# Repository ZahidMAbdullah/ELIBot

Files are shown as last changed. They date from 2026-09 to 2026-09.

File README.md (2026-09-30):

# ELIBot — Mechatronics Laboratory (Robot: Advanced)

**ELIBot** is a four-wheeled, all-terrain robot with spiked/clawed wheels, developed by a team of five undergraduate students for the *Mechatronics Laboratory (Robot: Advanced)* course at Kyoto University of Advanced Science (KUAS). Designed to navigate a challenging obstacle course—including a door, uneven terrain, slope, ditch, QR-code checkpoint, ledge, roller obstacle, speed bump, stairs, a traffic-light-controlled barrier, and an object-retrieval task—the robot combines a raised, high-clearance chassis, custom rigid/flexible claw wheels, and a lightweight single-DOF manipulator arm. It's primarily teleoperated from a remote operator station, watching fixed cameras placed along the course (plus an optional onboard camera feed), with support for minimal autonomous behaviors (e.g. reacting to the traffic light on its own) layered on top.

> This repository documents the full design process — from the original tri-wheel concept to the final ELIBot — along with its firmware, ROS2 software stack, CAD/print files, and build media.

## Table of Contents

- [Team](#team)
- [What It Was Built For](#what-it-was-built-for)
- [Design Journey](#design-journey)
- [Final Design](#final-design)
  - [Mechanical](#mechanical)
  - [Manipulator Arm](#manipulator-arm)
  - [Electronics](#electronics)
  - [Software Architecture](#software-architecture)
- [Operating Instructions](#operating-instructions)
- [Repository Structure](#repository-structure)
- [Documents](#documents)
- [Media](#media)
  - [Videos](#videos)
  - [Photos](#photos)
- [Acknowledgments & References](#acknowledgments--references)
- [License](#license)

## Team

**Team 12**, Mechatronics Laboratory (Robot: Advanced), Spring 2026:

- Abdullah Al Ayaat
- G. C. Mohnish
- Catherine Ella Burtenshaw
- Daphne Jillian Gan Tan
- Muhammad Abdullah Zahid

## What It Was Built For

Mechatronics Laboratory (Robot: Advanced) is a hands-on robotics course, run over one semester, where small teams design, fabricate, and program a robot from scratch. It culminates in a robot challenge held during the course's 15th week: a field of physical obstacles that every team's robot has to get through under its own power. ELIBot is this team's entry for that challenge.

The competition field laid out a mock "street" of obstacles a mobile robot has to get through under its own locomotion and, in places, its own manipulation — pushing/opening a door, climbing a slope, crossing uneven terrain and a ditch, reading a QR checkpoint, climbing down a ledge, crossing a speed bump and a roller, climbing up and down the stairs, responding correctly to a traffic light to get a barrier opened, and picking up and carrying an object to a goal. ELIBot's design — the raised chassis and clawed wheels in particular — was driven directly by that obstacle set.

The robot had to be untethered and was operated from a fixed station with no direct line of sight to the field — the operator watched a multi-window monitor fed by fixed cameras placed along the course, optionally supplemented by the robot's own onboard camera feed on a separate laptop — with a lightweight autonomous layer handling a few specific perception-driven behaviors (QR/traffic-light detection) on top of manual driving.

## Design Journey

ELIBot went through three distinct mechanical designs:

1. **Tri-wheel concept** (original pitch): a spring-suspended front "wheel-leg" (inspired by configurable wheel-leg mechanisms in the literature) for climbing stairs/ditches, a rear pair of wheels on a 4-bar spring suspension for uneven terrain, and a top-mounted 3-DOF manipulator arm with a solenoid-driven pincher gripper.
2. **Four-wheel, front-spiked only**: the tri-wheel base proved **unstable**, so the team pivoted to a four-wheeled layout — but only the front pair used spiked/clawed wheels, with plain wheels still at the rear.
3. **Four-wheel, all-spiked** (final): the plain rear wheels in design 2 didn't grip well enough to climb the stairs, so the team switched to spiked/clawed wheels on all four corners. The manipulator arm was also simplified from 3-DOF + pincher down to a lighter 1-DOF hook mechanism, for better weight distribution and stair-climbing stability.

Designs 1 and 2 are documented here only through their presentations — [`Robot Concept Presentation/`](./Robot%20Concept%20Presentation) for design 1 (the tri-wheel concept), and [`Intermediate Presentation/`](./Intermediate%20Presentation) for the transition from design 1 to design 2 — rather than through their raw CAD/design files. Design 3, the final version that was actually built, is described below, in the [final report](./Teams12_final_report.pdf), and via the source/print files elsewhere in this repository.

## Final Design

### Mechanical

ELIBot's body has three main parts:

- **Top Chassis / Bottom Chassis** — a simple box housing the microcontroller, motor drivers, buck converter, and perfboards, with a removable Top Chassis panel for easy access; sized to be sturdy against fall/testing impacts while still easy to open.
- **Brackets / Support Brackets** — front (shorter) and rear (taller) main brackets hold the drive motors, each secured in place by a matching support bracket; sized asymmetrically to keep the robot level, shrink its turning footprint, and shift the center of mass rearward for stair climbing without tipping.
- **Cage** — a lightweight top frame protecting the 12V LiPo battery, a power bank, and the Raspberry Pi 4, and keeping wiring organized.

The signature feature is the **clawed/spiked wheel**: a rigid **PLA** inner hub (bolted to the motor shaft via a threaded brass connector) paired with a flexible **TPU** outer ring of 8 claws. The rigid hub keeps the wheel stable while the TPU claws flex on impact and grip stair edges/ledges — giving some of the benefit of a reconfigurable wheel-leg design without its mechanical complexity.

### Manipulator Arm

The arm went through the same simplification arc as the chassis: an initial 3-DOF, top-mounted arm with a solenoid-driven pincher was replaced by a **1-DOF, front-mounted "elephant trunk"** arm ending in a curved hook — lighter, mechanically simpler, and strong enough to support the robot's own weight if it tips, unlike the original pincher which broke under load during testing. The final assembly uses three servos: one for base rotation, one for the second link, one for the hook.

### Electronics

| Component | Role |
|---|---|
| STM32 Nucleo-F091RC | Real-time motor/servo control (low-level) |
| Raspberry Pi 4 Model B | ROS2 high-level control, perception, decision-making |
| 2× L298N | Motor drivers for 4 brushed DC drive motors (skid-steering) |
| PCA9685 (16-ch) | PWM driver for 3 manipulator servos, over I²C |
| Buck converter | Steps down battery voltage for logic circuitry |
| 12V LiPo + power bank | Main drive power / Raspberry Pi power |
| USB camera | Onboard vision (QR codes, traffic light) |

The Pi and STM32 communicate over USB serial at 115200 baud: the Pi sends motion/servo setpoints, the STM32 executes deterministic PWM control and echoes actuator feedback. A watchdog on the STM32 stops all motors if commands stop arriving, preventing runaways from a dropped link.

For the full wiring/circuit diagram and electrical connections between all of these components, see §2.4 ("Circuit Design") of the [final report](./Teams12_final_report.pdf).

### Software Architecture

High-level software runs as a modular **ROS2** stack on the Raspberry Pi:

```
Operator (keyboard) ─┐
                      ▼
              Teleoperation Node ── USB Serial (115200) ──▶ STM32 (motors + servos)
                      │
USB Camera ──▶ Camera Publisher Node ──/camera/image_raw──▶ Vision Status Node
                                                                  │  QR (Pyzbar) + traffic light (YOLOv8 + HSV)
                                                                  ▼
                                                         /vision_status ──▶ LED Indicator Node (GPIO)
                                                                       └──▶ Traffic-light ROS2 notification (wireless, for the barrier)
```

- **Camera publisher** — captures RGB frames via OpenCV, keeps only the latest frame to avoid perception lag.
- **Vision status node** — runs QR detection (grayscale + Pyzbar) and traffic-light detection (YOLOv8n localizes the light, HSV classifies red/yellow/green) in parallel; debounces both before publishing state changes.
- **LED indicator node** — drives GPIO LEDs based on QR detection state.
- **Teleoperation node** — converts operator keyboard input into the STM32's serial command protocol.

Firmware protocol (STM32 side): 8 slash-separated values — 4 motor duty cycles `[-1.0, 1.0]` and 4 servo angles (degrees) — terminated by `d`, e.g. `0.5/0.5/0/0/90/0/0/-45d`. See [`source-code/Nucleo_Firmware/combined_node/README.md`](./source-code/Nucleo_Firmware/combined_node/README.md) for the full protocol and pin mapping.

## Operating Instructions

1. Connect the STM32 to the Raspberry Pi 4; power the Pi from the power bank.
2. (Setup/debug) Connect via HDMI to a monitor, or view the Pi's desktop remotely, to launch ROS2 nodes from a terminal.
3. Launch, in order:
   1. `ros2 launch elibot_vision qr_led.launch.py` → starts the camera publisher, vision status node, and QR LED indicator together
   2. `ros2 run elibot_robot_ctrl motorservo_teleop_controller --port /dev/ttyACM0` → keyboard teleop, sends serial commands to the STM32
4. Disconnect the setup peripherals, connect the drive battery, and verify wheel + arm motion before running the course.

Full build/run instructions and dependencies: [`source-code/README.md`](./source-code/README.md). Full narrative details: [final report, §3](./Teams12_final_report.pdf).

The vision node can also run off-robot on a separate, more powerful machine over the network instead of on the Pi — see [`source-code/README.md`](./source-code/README.md#3-vision-node-onboard-vs-remote-deployment) for that configuration (`elibot_ros2_ws_server/`), which was used during development to experiment with heavier detection models than the Pi could run in real time.

## Repository Structure

```
.
├── README.md
├── LICENSE
├── Teams12_final_report.pdf
├── Robot Challenge and Field Details 2025.pdf
├── Robot Concept Presentation/       # superseded tri-wheel concept pitch — not the final design
├── Intermediate Presentation/        # mid-project checkpoint — shows the tri-wheel -> four-wheel transition
├── STL Files/                        # final ELIBot print files (STL), organized by body/wheels/manipulator
├── source-code/                      # firmware + ROS2 software — see its own README
│   ├── Nucleo_Firmware/              # STM32 firmware (PlatformIO/mbed): combined_node (final), motors_only/servos_only (debug isolation builds)
│   ├── elibot_ros2_ws_robot/         # ROS2 workspace deployed ON the Raspberry Pi (camera, vision, teleop)
│   └── elibot_ros2_ws_server/        # optional: vision node deployable on a separate, more powerful machine instead of the Pi
└── Media/                            # photos and video (large raw footage hosted externally)
```

## Documents

- [Final report](./Teams12_final_report.pdf) — full design writeup (this README summarizes it)
- [Challenge & field rules](./Robot%20Challenge%20and%20Field%20Details%202025.pdf)
- [Concept presentation](./Robot%20Concept%20Presentation/Concept%20Presentation%20%28Superseded%20Tri-Wheel%20Design%29.pdf) — the original tri-wheel pitch; **superseded**, describes a different robot than the one that was actually built
- [Intermediate presentation](./Intermediate%20Presentation/Intermediate%20Presentation%20%28Design%20Transition%20Checkpoint%29.pdf) — a mid-project checkpoint documenting the pivot from the tri-wheel design to the second, four-wheel design (front wheels spiked, rear wheels still plain); that rear-wheel choice and the manipulator's pincher end effector shown here were both changed again before the final design
- [Final presentation video (Week 15)](https://drive.google.com/file/d/1nr6MhxmOqBarv2mEdx8B2zVPzM3RgYNS/view?usp=drive_link) — the team's video presentation of the finished robot, made right before the competition run (hosted on Google Drive; not tracked in this repo due to file size)

## Media

### Videos

- [Stage I practice run](https://drive.google.com/file/d/1u3so2-tLWOBUojRxOy6DUSRT6eiabuuC/view?usp=sharing) — a full practice run (not the official one) of ELIBot completing the Stage I challenge track ahead of the competition (hosted on Google Drive; not tracked in this repo due to file size)
- [Stage II official run (Week 15)](https://drive.google.com/file/d/196SE-jIKrzIXMWrg3RmbG3_Q3yIPCxZ9/view?usp=sharing) — full video of ELIBot's official run on the challenge field for Stage II of the competition (hosted on Google Drive; not tracked in this repo due to file size)
- [Full event livestream (Week 15)](https://www.youtube.com/live/wm4ukXukuMc) — the university's official broadcast of the entire robot challenge event, covering all teams, not just ELIBot's run. This team's segments:
  - [1:34:22](https://www.youtube.com/live/wm4ukXukuMc?t=5662s) – 1:37:34 — team introduction and the idea behind the robot's design
  - [1:37:34](https://www.youtube.com/live/wm4ukXukuMc?t=5854s) – 1:43:20 — Stage I run
  - [3:35:19](https://www.youtube.com/live/wm4ukXukuMc?t=12919s) – 3:43:02 — Stage II run
  - [3:43:02](https://www.youtube.com/live/wm4ukXukuMc?t=13382s) – 3:45:35 — post-run team interview

### Photos

Final prototype, as built (see [`Media/Pictures/Robot Pictures/`](<./Media/Pictures/Robot Pictures>) for the originals):

<p align="center">
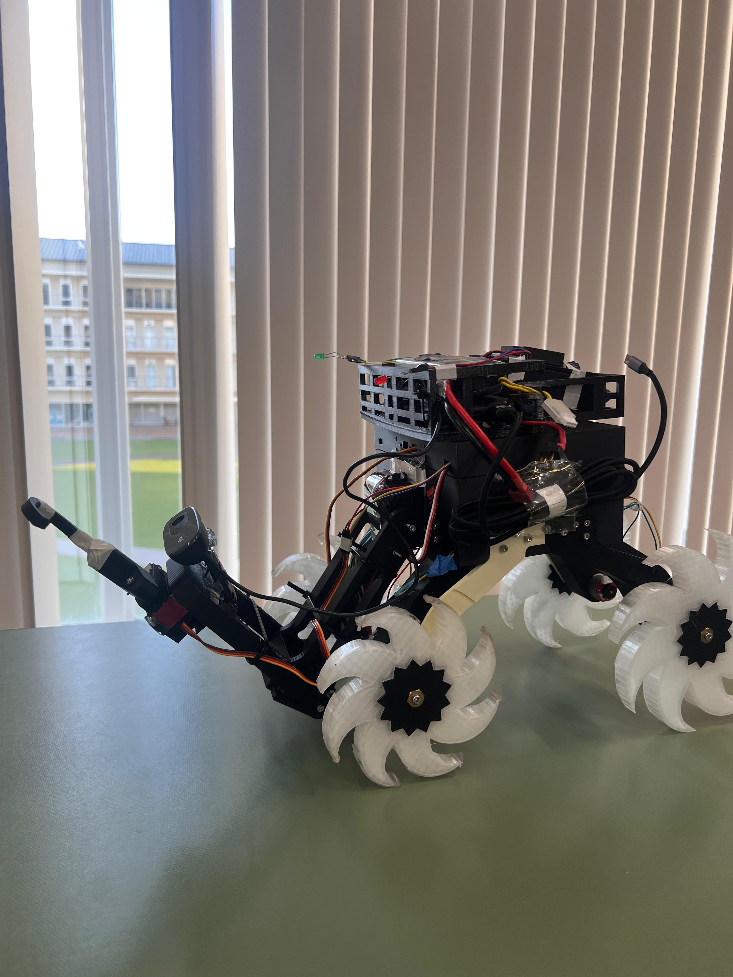
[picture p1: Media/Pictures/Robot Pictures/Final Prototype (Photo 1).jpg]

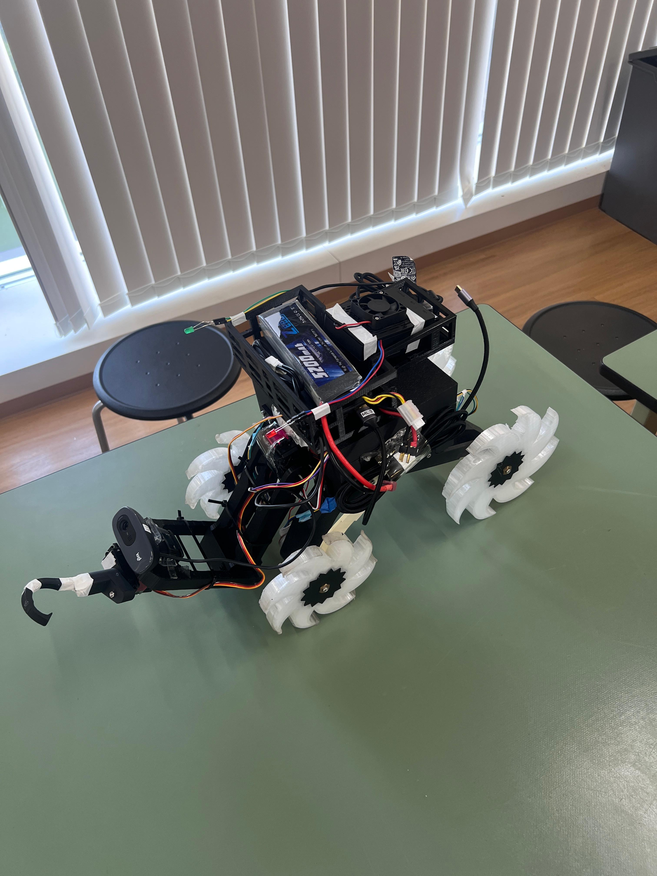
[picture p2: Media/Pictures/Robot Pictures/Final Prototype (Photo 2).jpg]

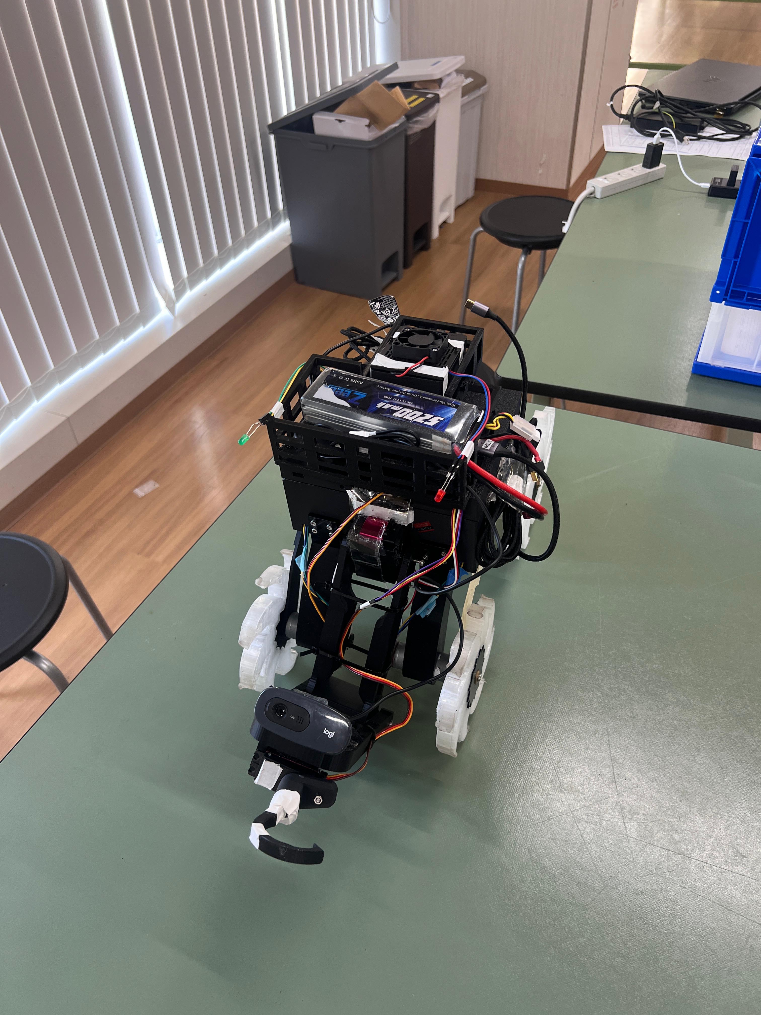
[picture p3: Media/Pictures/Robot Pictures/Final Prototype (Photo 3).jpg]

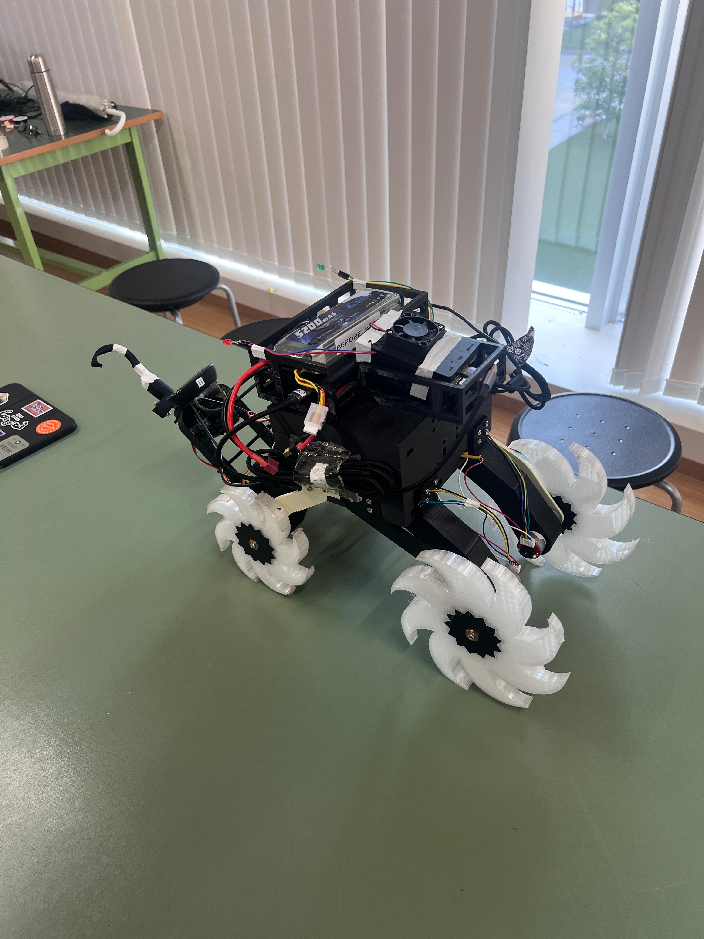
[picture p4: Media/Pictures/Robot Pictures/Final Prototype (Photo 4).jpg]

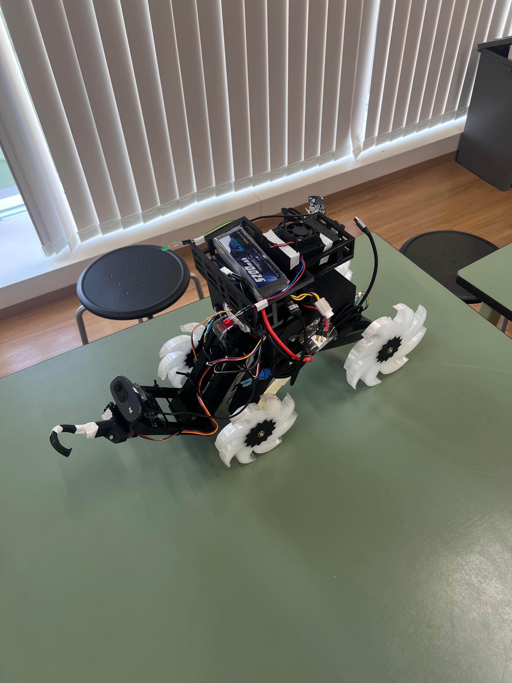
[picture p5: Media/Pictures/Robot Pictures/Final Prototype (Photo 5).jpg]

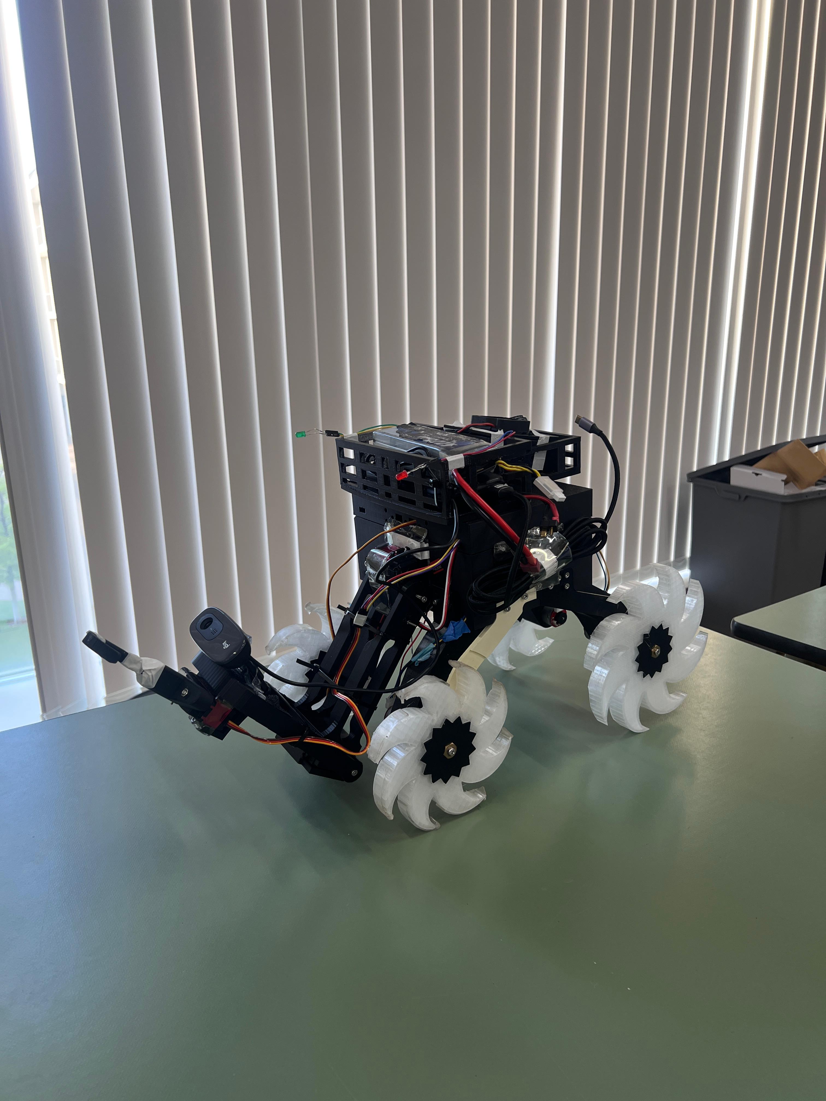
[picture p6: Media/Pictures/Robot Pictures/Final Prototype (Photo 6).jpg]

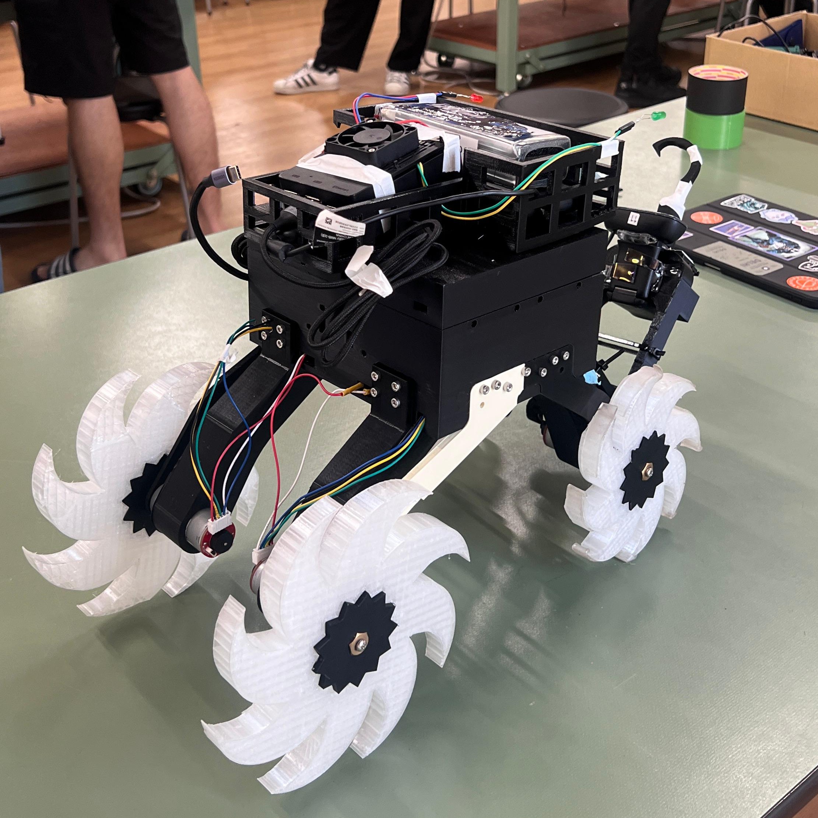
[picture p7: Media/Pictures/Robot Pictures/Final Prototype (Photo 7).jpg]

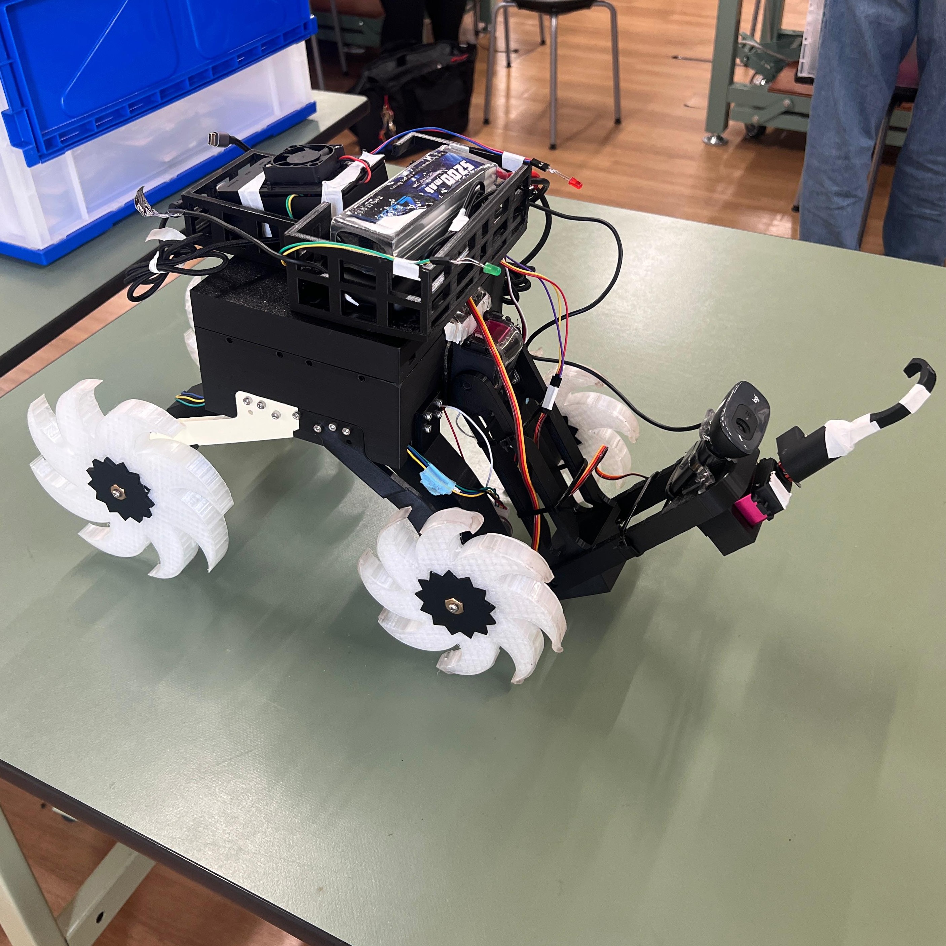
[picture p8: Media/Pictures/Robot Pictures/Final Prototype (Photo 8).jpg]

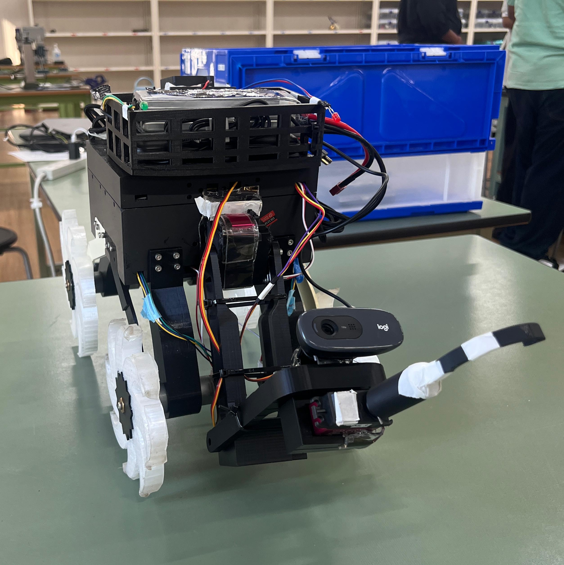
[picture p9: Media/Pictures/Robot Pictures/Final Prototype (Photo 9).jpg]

</p>

Team 12, with ELIBot, at the Week 15 competition (left to right: Muhammad Abdullah Zahid, Catherine Ella Burtenshaw, G. C. Mohnish, Abdullah Al Ayaat, Daphne Jillian Gan Tan):

<p align="center">
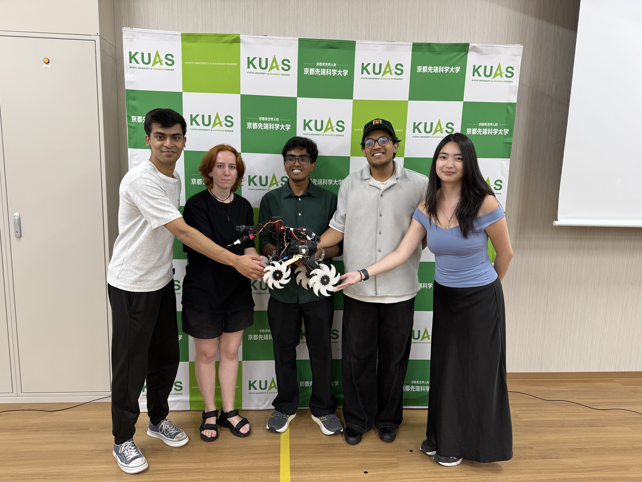
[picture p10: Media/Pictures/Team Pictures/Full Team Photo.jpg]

</p>

## Acknowledgments & References

Built for the Mechatronics Laboratory (Robot: Advanced) course, Kyoto University of Advanced Science, Spring 2026.

The clawed-wheel concept was inspired by prior work on configurable wheel-legs:

1. R. Sell, G. Aryassov, A. Petritshenko, and M. Kaeeli, "Kinematics and dynamics of configurable wheel-leg," in *Proc. 8th Int. DAAAM Baltic Conf. Industrial Engineering*.
2. C. Zheng and K. Lee, "Wheeler: Wheel-leg reconfigurable mechanism with passive gears for mobile robot applications," in *Proc. IEEE Int. Conf. Robotics and Automation (ICRA)*.

## License

This project is licensed under the [MIT License](./LICENSE).

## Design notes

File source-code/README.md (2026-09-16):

# ELIBot Source Code

This folder contains everything that runs on ELIBot: the STM32 firmware and the ROS2 software stack. See the [project README](../README.md) for the overall hardware/software architecture — this document is about building and running the code.

## Layout

```
source-code/
├── Nucleo_Firmware/           # STM32 firmware (PlatformIO/mbed) — see its own README
│   ├── combined_node/         # final firmware: 4 motors + 3 servos
│   ├── motors_only/           # debug isolation build: motors only
│   └── servos_only/           # debug isolation build: servos only
├── elibot_ros2_ws_robot/      # ROS2 workspace deployed ON the robot's Raspberry Pi 4
│   └── src/
│       ├── elibot_camera/     # USB camera -> /camera/image_raw
│       ├── elibot_vision/     # QR + traffic-light detection, LED indicator
│       └── elibot_robot_ctrl/ # evdev keyboard teleop -> STM32 serial
└── elibot_ros2_ws_server/     # optional: remote-compute deployment of the vision node (see below)
    └── src/elibot_vision/
```

## Prerequisites

- **Firmware**: [PlatformIO](https://platformio.org/) (CLI or the VS Code extension). No other toolchain needed — `platform = ststm32`/`framework = mbed` pulls in the rest.
- **ROS2**: built and tested against **ROS2 Humble** on the Raspberry Pi (Ubuntu). `colcon` for building.
- **Python packages** (install via `pip3` on top of the ROS2 Python env):
  ```
  pip3 install opencv-python pyserial evdev pyzbar ultralytics gpiozero
  sudo apt-get install libzbar0   # native dependency of pyzbar
  ```
  (`cv_bridge`, `sensor_msgs`, `rclpy` etc. come from the ROS2 Humble install itself.)

## 1. Firmware — build & flash

```
cd Nucleo_Firmware/combined_node
pio run              # build
pio run -t upload    # flash via ST-Link
```

See [`Nucleo_Firmware/README.md`](./Nucleo_Firmware/README.md) for the three firmware variants, and [`Nucleo_Firmware/combined_node/README.md`](./Nucleo_Firmware/combined_node/README.md) for the full serial protocol, pinout, and wiring notes.

## 2. Robot-side ROS2 workspace — build & run

On the Raspberry Pi:

```
cd elibot_ros2_ws_robot
colcon build
source install/setup.bash
```

Four nodes make up the running system (see the [project README](../README.md#software-architecture) for the data flow diagram):

```
# Camera + vision + QR LED indicator, together:
ros2 launch elibot_vision qr_led.launch.py

# Teleop (separate terminal — needs the STM32 connected, e.g. /dev/ttyACM0):
ros2 run elibot_robot_ctrl motorservo_teleop_controller --port /dev/ttyACM0
```

Teleop controls (forwarded raw to the STM32, which owns all interpretation):

```
Motors: w=forward  s=backward  a=strafe/turn-left  d=strafe/turn-right  q=stop
Speed:  0-9 = 10%-100% (default 7 = 80%)
Servos: u/j=servo1±  i/k=servo2±  o/l=servo3±  p/;=servo4±  c=center all
```

## 3. Vision node: onboard vs. remote deployment

`elibot_vision`'s vision-status node (QR + traffic-light detection) can run two ways:

- **Onboard (default, competition configuration)** — `elibot_ros2_ws_robot/src/elibot_vision/elibot_vision/vision_status_node.py` runs directly on the Raspberry Pi, launched via `qr_led.launch.py` above. It's optimized for the Pi's weaker CPU: detection runs on its own thread (decoupled from the ROS executor) and the YOLOv8n model is exported to NCNN for faster inference.
- **Remote/offboard (optional, used during development)** — `elibot_ros2_ws_server/src/elibot_vision/elibot_vision/vision_status.py` is the same node, meant to run on a separate, more powerful machine (e.g. a laptop) instead of the Pi, useful when experimenting with heavier detection models than the Pi can run in real time. It publishes to the exact same topic/schema, so it's a drop-in replacement: run this on the remote machine, and the Pi only needs `elibot_camera` (to publish `/camera/image_raw`) and `elibot_vision`'s `qr_led_indicator.py` (to react to `/vision_status`) running locally. Both machines must be on the **same ROS2 domain** and reachable over the network — set `ROS_DOMAIN_ID` to match on both, and use a dedicated wireless link/router rather than a general venue wifi network (which may block the multicast traffic ROS2 discovery needs).

To build/run the remote variant:
```
cd elibot_ros2_ws_server
colcon build
source install/setup.bash
ros2 run elibot_vision vision_status
```

## Notes

- `yolov8n.pt` (the pretrained YOLOv8n weights) is intentionally not tracked in this repo — `ultralytics` auto-downloads it on first run if missing. It's identical in both ROS2 workspaces.
- Each firmware project's `.pio/` directory and the ROS2 `build`/`install`/`log` directories are build artifacts and are not tracked in git (see [`.gitignore`](../.gitignore)); regenerate them locally with `pio run` / `colcon build`.

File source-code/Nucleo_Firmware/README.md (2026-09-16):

# Nucleo_Firmware

PlatformIO/mbed firmware for the STM32 Nucleo-F091RC that drives ELIBot's 4 drive motors and 3 manipulator servos. Three build targets live here:

| Project | Purpose |
|---|---|
| **`combined_node/`** | **The final firmware.** Controls all 4 DC motors (open-loop PWM via 2× L298N) and all 3 servos (via a PCA9685 I2C board) together, over one USB-serial link. This is what ships on the robot. |
| `motors_only/` | Debug isolation build — motors and the serial protocol only, no servo/PCA9685 subsystem. Extracted verbatim from `combined_node` to check whether a motor problem is specific to running motors and servos together (shared power rail / brownout) or exists on its own. |
| `servos_only/` | Debug isolation build — servos and the serial protocol only, no motor subsystem. Same idea as `motors_only`, for isolating servo/I2C problems. |

All three share the same serial command protocol (see `combined_node/README.md`) and the same hold-to-move/watchdog behavior; `motors_only` and `servos_only` are kept in sync with `combined_node`'s key mappings so a bug reproduced in isolation reflects the same behavior in the combined firmware.

## Building

Each project is a standalone PlatformIO project:

```
cd combined_node        # or motors_only / servos_only
pio run                 # build
pio run -t upload       # flash via ST-Link
```

## Shared libraries (`lib/`)

- **`PWMMotor`** — open-loop PWM H-bridge motor driver (no encoder/PID), used by `combined_node` and `motors_only`.
- **`PCA9685`** — driver for the 16-channel I2C PWM board used to generate all 3 servo signals, used by `combined_node` and `servos_only`.
- **`ros2mbed` (`SerialROS2`)** — the serial command parser shared by all three projects.

Two earlier servo-driving approaches — a hardware-`PwmOut`-based `Servo` class, then a bit-banged-GPIO `SoftServo` — were tried before settling on the PCA9685 board (freeing up GPIO pins and sidestepping the Nucleo-F091RC's limited free PWM timers) and have since been removed from `combined_node/lib`, since neither is `#include`d by the final firmware.

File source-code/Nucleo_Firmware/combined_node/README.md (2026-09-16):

# combined_node

Firmware for the Nucleo-F091RC that controls **4 DC motors** (open-loop PWM,
taken unchanged from `mbed_node`) and **4 RC servos**, all commanded over one
serial link (ST-Link virtual COM port, 115200 baud).

## Pinout

### Motors (unchanged from mbed_node)
| Motor | Forward | Backward |
|---|---|---|
| 1 | PA_8 | PA_9 |
| 2 | PC_6 | PC_7 |
| 3 | PB_14 (ALT0) | PB_15 (ALT1) |
| 4 | PA_4 | PA_6 (ALT0) |

### Servos (new)
| Servo | Pin |
|---|-----|
| 1 | PB_9 |
| 2 | PB_8 |
| 3 | PB_11 |
| 4 | PA_7 |

Servos are driven by **`SoftServo`** (`lib/SoftServo`), a bit-banged PWM
implementation using `Ticker` + `Timeout`, not mbed's hardware `PwmOut`.
This is a deliberate design choice, not a workaround of convenience:

- Every STM32 timer with more than one channel is already claimed by the
  4 motors (TIM1, TIM3, TIM14, TIM15, TIM16), and a timer's period is
  shared across all of its channels — a servo sharing a motor's timer
  would corrupt one or the other's PWM frequency.
- `TIM2`, which pins like `PB_10`/`PB_11`/`PA_0`/`PB_3` map to, is reserved
  internally by mbed OS as the microsecond ticker and has **no PWM pin
  mapping at all** on this target (`PeripheralPins.c` has every TIM2 row
  commented out). Constructing a hardware `Servo` on one of those pins
  hits an invalid pinmap lookup and asserts at boot — before the serial
  link even comes up, so the whole board appears dead, not just the servo.
- After the motors, only one hardware PWM channel remains free on this
  chip (TIM17, one channel) — not enough for 4 independent servos.

`SoftServo` sidesteps all of this: `Ticker`/`Timeout` are OS-level
scheduled callbacks, not exclusive timer ownership, so they work on any
plain GPIO without colliding with the motors or mbed's internal timing.
That means the servo pins above can be **any** free GPIO — they don't
need to be PWM-capable, so wiring isn't constrained by the chip's timer
map.

Power the servos and motors from an external supply, not the Nucleo's 5V
pin; connect the supply ground to the Nucleo GND.

## Serial protocol

**Command** (host → board): 8 values separated by `/`, terminated by `d`:

```
<duty1>/<duty2>/<duty3>/<duty4>/<ang1>/<ang2>/<ang3>/<ang4>d
```

- Duties: motor duty cycle in `[-1.0, 1.0]` (negative = reverse, 0 = stop)
- Angles: servo position in degrees, `[-servo_range, +servo_range]`
  (default ±135° for the 8125MG; edit `servo_range[]` in `src/main.cpp`)

Example — motors 1+2 forward at 50%, servo 1 to +90°, servo 4 to −45°:

```
0.5/0.5/0/0/90/0/0/-45d
```

Always send all 8 values. The onboard LED toggles each time a command is
parsed.

**Feedback** (board → host): current setpoints echoed continuously as one
comma-separated line, duties first, then angles:

```
0.50,0.50,0.00,0.00,90.0,0.0,0.0,-45.0
```

## Build & flash

```
pio run              # build
pio run -t upload    # flash via ST-Link
```

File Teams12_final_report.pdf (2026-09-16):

# Mechatronic Laboratory (Robot: Advanced) Team 12:

A.Abdullah Al
B.Catherine
TAN Daphne
Z.Md. Abdullah
G.C.Mohnish

Team 12 Report

# 1.Introduction

Our design is based on a four wheeled mobile robot with a unique claw or spiked wheel design combined with a raised chassis for high ground clearance. Taking advantage of the high stability, easy control, strong traction and high payload capacity of the 4-wheel design, we aim to overcome most of the obstacles and challenges in this robot challenge. Our main motivation was to design and fabricate a robot from scratch, as well as learn all the skills, knowledge, and understanding necessary to realize this goal. The originality of our robot lies in its spiked or claw-inspired wheel and its chassis design.

The spiked wheel, although at first looks orthodox, works well in overcoming most of the obstacles such as the uneven terrain, ditch, double roller and stairs. Similarly, our unique chassis design includes the brackets that hold our wheels as well as the body that holds the electronic circuit and hardware of our robot. At first glance the design may look straightforward but it has gone through multiple reversions to give us the most optimal design that enables us to overcome the remaining obstacles without much hassle.

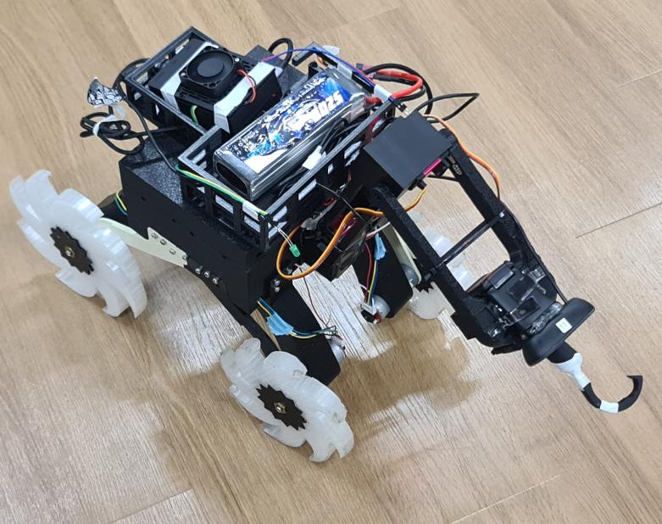
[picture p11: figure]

Figure I. Final Prototype of ELIBot

# 2. System Overview

## 2.1 Hardware Design: -

ELIBot's main body consists of three main components: the brackets that hold the brushed DC motors, the chassis that houses all the electronics including the microcontroller, motor drivers, and perfboards, as well as the cage that protects important components such as the Raspberry Pi 4 and the power bank.

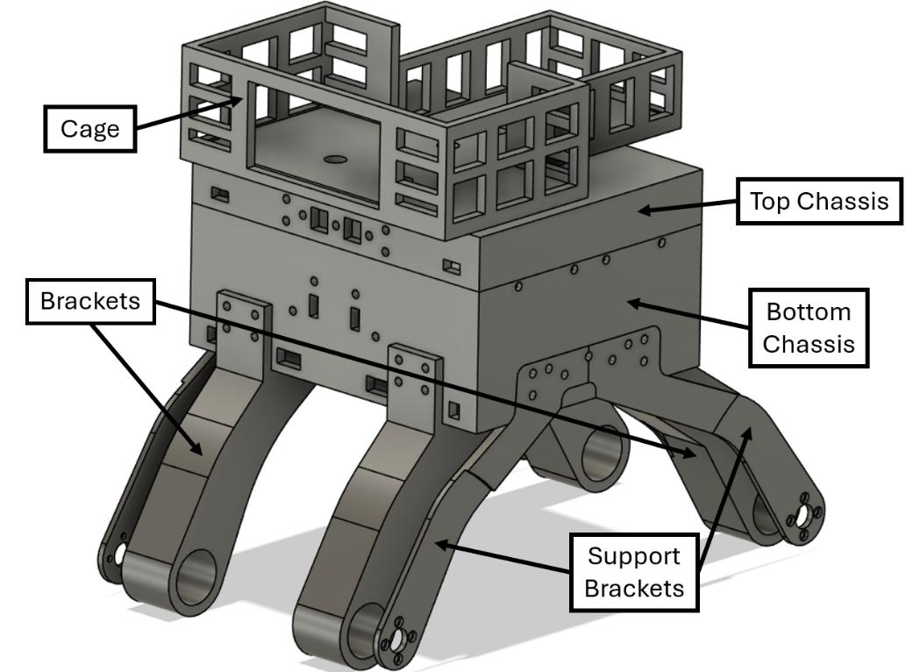
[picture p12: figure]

Figure II. Components of ELIBot Structural Design

### 2.1.1 Brackets: -

There are two types of brackets: main brackets and support brackets. The front main brackets are slightly shorter than the rear brackets, which serve multiple purposes such as helping in maintaining a consistent overall height, reducing the robot's overall footprint for a smaller turning radius, and compensating for the smaller clawed wheel used at the front compared to the back. Similarly, the front support brackets are shorter than the rear ones, as means of ensuring that both motors remain aligned, whilst also shifting the center of mass when climbing higher gradient surfaces such as the stairs and ditch, so that the robot did not tip over backwards due to weight distribution. The main purpose of both brackets however, is to provide stability and to hold the brushed DC motors in place when the clawed wheels make contact with the ground. All brackets are mounted to the chassis using M3 bolts and nuts, with each motor placed in the main bracket and secured by the support bracket. The support brackets further incorporate screw holes at they’re ends, enabling each motor to be screwed in place to the bracket, prevents unwanted twisting of the motors and allowing all rotational torque to be used for turning the wheels.

### 2.1.2 Chassis: -

The chassis is a simple box design with a removable lid on top for easy access to the circuit and all internal components, such as the microcontroller, motor drivers, buck converters, and servo motor driver, allowing for easy adjustment or alteration. The chassis was built to be sturdy, not only to handle falls or failed attempts at clearing obstacles during testing, but also to protect all the internal components and circuitry during testing and throughout the robot challenge. Multiple holes where also included in the bodies design to allow for easy wired connections between the external motors and internal circuitry.

### 2.1.3 Cage: -

The main purpose of the cage is to protect and hold three main components, i.e. a 12V LiPo battery, a power bank, and the Raspberry Pi 4 Model B as well as their various connections, ensuring that the wires don't get loose or sustain any unforeseen damage during testing. Apart from protection, the cage also helps keep all the components in place and the wires organized for better management, so that they don't get in the way of the robot's locomotion. A lightweight design was chosen to reduce any unnecessary additional weight, which could have impacted the robots function.

## 2.2 Clawed Design

The clawed design was inspired by the configurable wheel design [1][2], which has two forms: a closed configuration and an open
configuration. With the help of gears, the wheel can dynamically switch between the two configurations

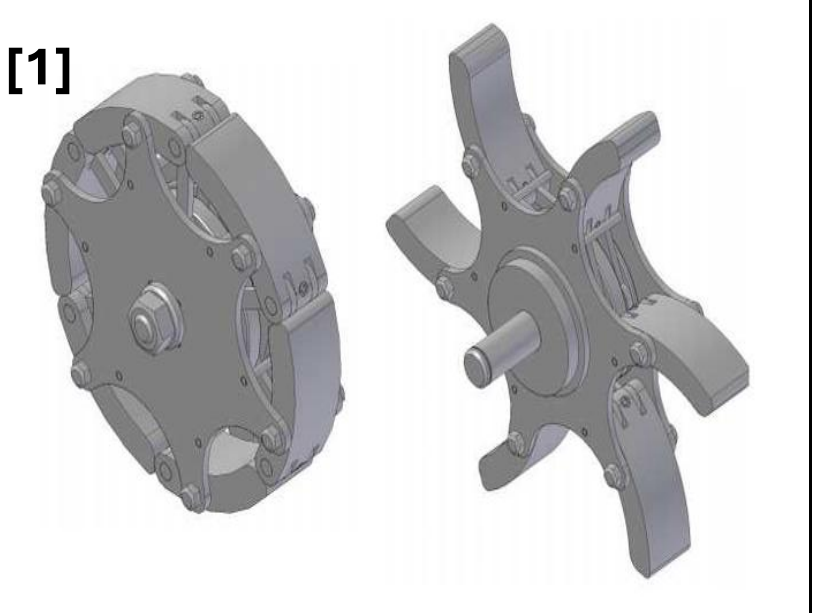
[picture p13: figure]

Although we initially considered going with the configurable design, we believed it was unnecessary for our wheel to switch between two states, and that a semi-open form would be sufficient to overcome the course and its obstacles. The main drawback of this decision was that it would cause jittery locomotion; however, the benefit was that it allowed us to follow a simpler design and fabrication process, without needing a complex gear mechanism or extra motors to not only rotate the wheel but also open and close it. Because of this quicker fabrication process, we were able to test a variety of wheels of different sizes, thicknesses, and materials until we found one that allowed us to complete the track.

The clawed wheel consists of two parts: an outer part and an inner part. The outer part is fabricated out of TPU95A with 8 claws, forming a circular wheel-like shape, whereas the inner part, which is attached to the DC motor via a shaft, allows the outer wheel to be attached, switched, or replaced easily without removing the shaft. A thread based-brass connector was used to attach to the shaft with sealant used to prevent the vibrations of the motor from loosening the threads, therefore preventing the wheel from falling off during testing and the robot challenge. The inner part of the wheel was designed to tightly fit the brass connector, and prevent it from moving. Due to the design of the connectors, specifically placed holes/gaps where incorporated into the inner wheels design so that the threads could be tightened from the outside using a simple L-shaped Allen key.

The wheel was also designed this way because a wheel made entirely out of TPU would be prone to deformation across the whole structure, due to the flexible nature of TPU. By instead fabricating the core, or inner part, out of PLA, the claws are able to deform on impact or when overcoming an obstacle such as uneven terrain or stairs, while the wheel as a whole remains stable, thanks to the rigid plastic core.

TPU was chosen due to its non-rigid nature, granting the outer wheel a degree of flexibility that otherwise would not be possible with other materials. Building the outer-wheel with this allowed for more adaptability to the course, as the TPU was capable of acting as a mild shock absorber when tackling obstacles such as the ledge and going down the stairs, whilst the materials properties, as well as gaps in the wheels claws helps maintained stability (such as when crossing the uneven terrain).

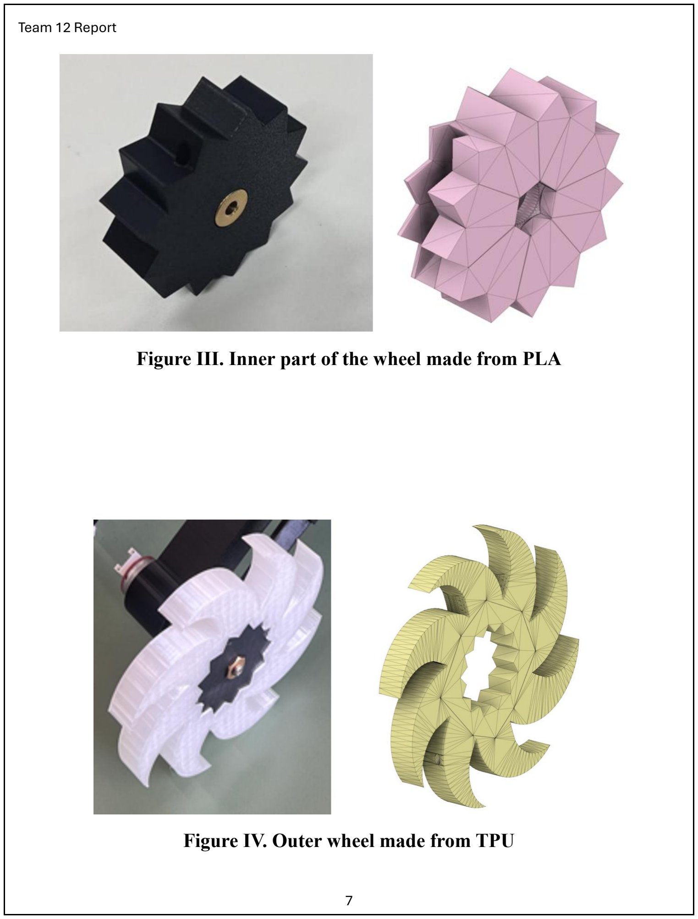
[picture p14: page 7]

Figure III. Inner part of the wheel made from PLA

Figure IV. Outer wheel made from TPU

## 2.3 Manipulator Arm: -

The manipulator arm underwent several design iterations throughout the development process. The initial design was mounted on the top of the robot and featured three degrees of freedom (3-DOF). As the robot design evolved, the manipulator was redesigned to be lighter, more durable, and mechanically simpler. It was relocated to the front of the robot, where it functioned as an elephant trunk-like mechanism. The design was simplified to a single degree of freedom (1-DOF), reducing the robot's overall weight while improving front weight distribution. This enhanced the robot's stability, particularly when climbing and descending stairs.

The end effector also evolved during the design process. The original gripper design was unable to withstand the forces experienced during testing, especially when the robot tipped over. As a result, it was replaced with a curved hook that was stronger and capable of supporting the robot's weight without damage. The final manipulator assembly consisted of three motors: one at the base for arm rotation, one driving the second link, and one rotating the hook for object retrieval. This final configuration provided a lightweight, durable, and reliable solution for the robot's object manipulation tasks.

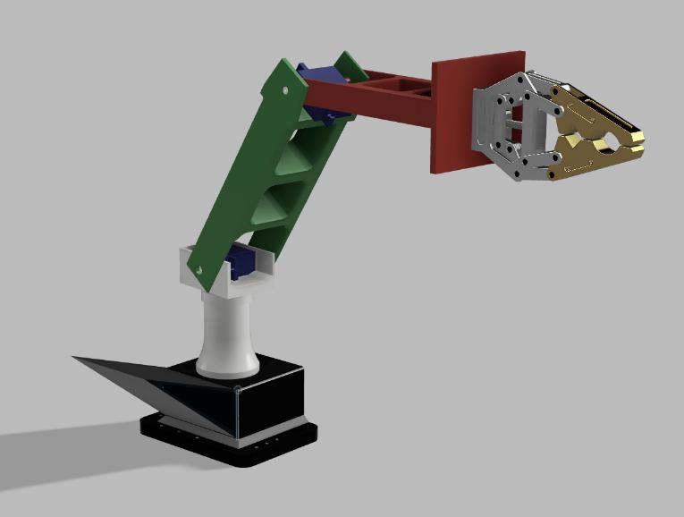
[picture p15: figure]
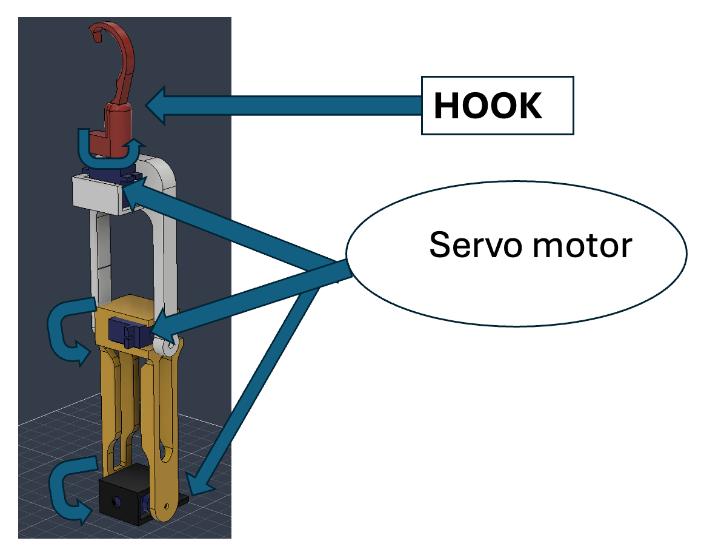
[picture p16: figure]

Initial design | Final design
Figure V. Manipulator Arm

## 2.4 Circuit Design: -

ELIBot is a 4-wheeled mobile robot equipped with a 2-degree-of-freedom manipulator arm, enabling it to both navigate its environment and manipulate objects within it. This dual functionality means ELIBot's electronics must handle two distinct actuation demands simultaneously: driving the four wheels for locomotion and articulating the arm for manipulation tasks.

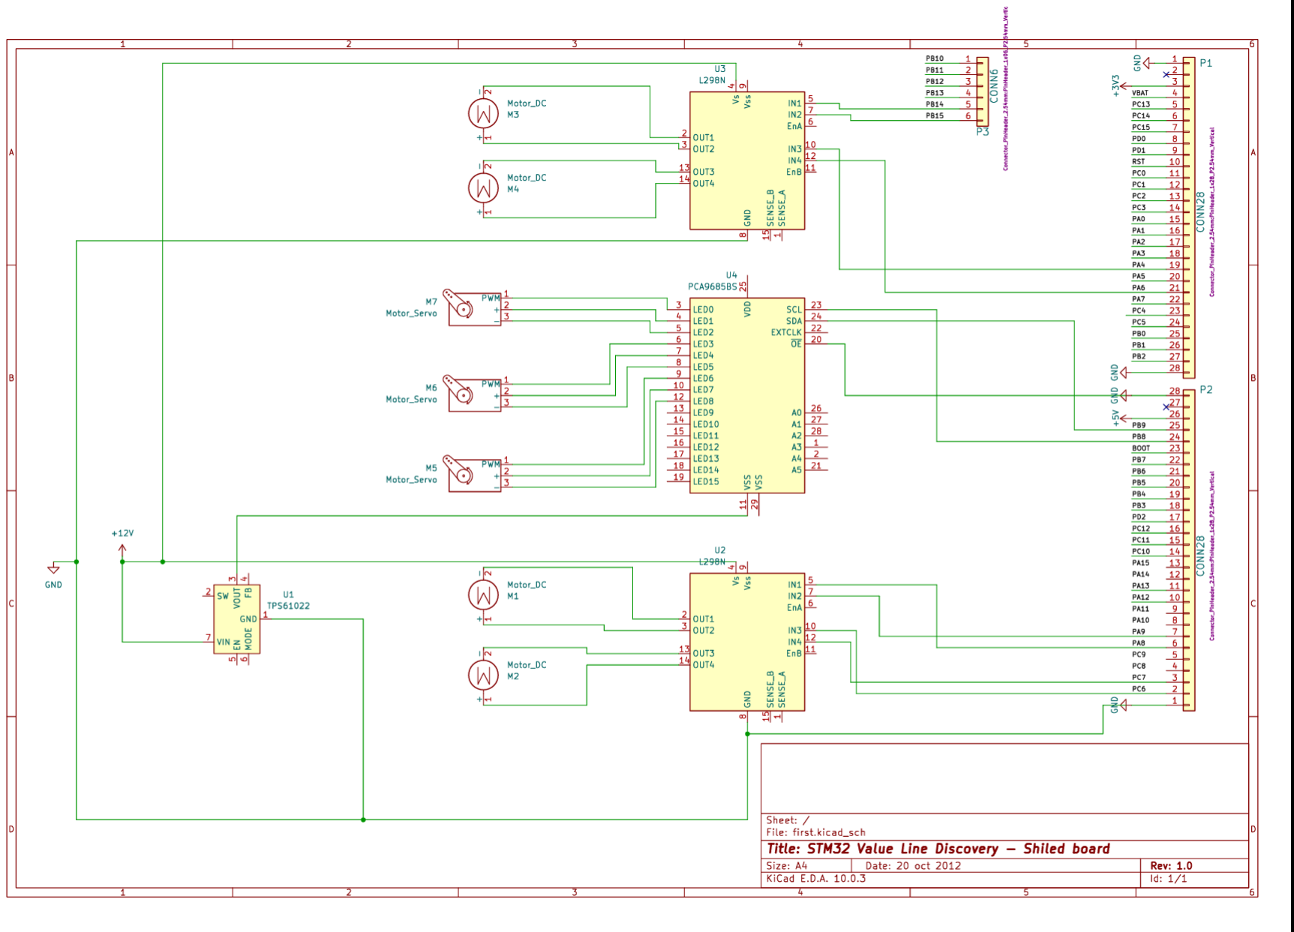
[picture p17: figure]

Figure VI. Overall Circuit Design used in ELIBot

As a result, ELIBot requires a circuit capable of not only powering and controlling four brushed DC motors, but also three servo motors, each with different control requirements and current draws. The four brushed DC motors handle the robot's mobility, driving the wheels via skid steering, while the three servo motors provide the joints of the manipulator arm, allowing it to reach, pivot, and grip.

To meet these requirements, the above circuit consists of four brushed DC motors, three servo motors, two L298N motor drivers, one PCA9685 16-channel servo driver, a buck converter, an STM32 NUCLEO-F091RC microcontroller, and a Raspberry Pi 4 Model B for controlling the different nodes. The two L298N drivers handle the higher current and bidirectional control needed for the DC motors, while the PCA9685 offloads precise PWM signal generation for the three servos, freeing up processing resources on the microcontroller. The buck converter steps down the main battery voltage to a stable, regulated level suitable for the logic circuitry, protecting sensitive components from voltage fluctuations. Together, the STM32 NUCLEO-F091RC and Raspberry Pi 4 form a two-tier control architecture, with the STM32 handling low-level, time-critical motor control and the Raspberry Pi managing higher-level decision-making and coordination between subsystems.

## 2.5 Software and Control

## The software architecture of ELIBot is designed using a hierarchical control structure that separates high-level decision making from low-level actuator

control, as illustrated in Figure VII.

## High-level software is executed on the Raspberry Pi 4 Model B using the Robot Operating System 2 (ROS2), while the STM32 NUCLEO-F091RC

microcontroller performs real-time control of the robot actuators.

Communication between the two processors is established through a USB serial interface operating at 115200 baud, enabling the Raspberry Pi to transmit control commands while the STM32 executes deterministic motor and servo control. This distributed architecture reduces the computational burden on the microcontroller while allowing computationally intensive

perception algorithms to execute on the Raspberry Pi.

### 2.5.1 Robot Motion Control

The robot motion control system adopts a two-layer architecture in which the Raspberry Pi functions as the high-level controller and the STM32 serves as the real-time actuator controller. A dedicated ROS2 teleoperation node running on the Raspberry Pi receives keyboard input from the operator and converts it into

compact serial commands that are transmitted to the STM32.

Upon receiving a command, the STM32 interprets the requested motion and independently controls the direction and speed of the robot actuators. The four DC

## drive motors are driven using pulse-width modulation (PWM) through two L298N motor drivers, implementing skid-steering locomotion by independently controlling the left and right wheel pairs. Motion commands determine the direction of rotation, while selectable PWM duty-cycle levels regulate the

travelling speed of the robot.

The manipulator arm is actuated by three servo motors controlled through a PCA9685 16-channel PWM driver connected via the I²C interface. Rather than commanding abrupt position changes, the controller updates the desired joint positions incrementally while enforcing predefined mechanical limits for each joint. A slew-rate limiter gradually moves each servo towards its target position at a controlled angular velocity, producing smoother manipulator motion and

reducing unnecessary mechanical stress on the servos.

## To improve operational safety, the STM32 continuously monitors the arrival of motion commands through a watchdog mechanism. If communication with the Raspberry Pi is interrupted or no valid control command is received within

the specified timeout period, the controller immediately stops all drive motors.

## This prevents unintended robot movement caused by communication failures

or unexpected termination of the teleoperation software.

### 2.5.2 Vision Processing Pipeline

## Robot perception is implemented as a modular ROS2 vision pipeline consisting of independent camera acquisition, perception, and status indication nodes. This modular publisher-subscriber architecture allows each processing stage to operate independently while exchanging information

through ROS2 topics, simplifying debugging and future software expansion.

The camera publisher node continuously captures RGB images from the onboard USB camera using OpenCV and publishes them to the /camera/image_raw topic together with camera information. To reduce perception latency, the camera interface is configured to retain only the most recent captured frame, preventing outdated images from accumulating when image processing temporarily requires more time than the camera frame

interval.

The published image stream is processed by the vision status node, which simultaneously performs QR code recognition and traffic light detection. QR code detection is implemented using the Pyzbar library after converting each image to grayscale. During software development, additional preprocessing techniques, including contrast enhancement and image upscaling, were evaluated; however, experimental testing showed no improvement in detection performance compared with direct grayscale decoding while increasing computational cost. Consequently, the final implementation performs QR

recognition directly on the grayscale image.

## Traffic light recognition is implemented using a hybrid detection approach. A YOLOv8 object detection model first identifies the location of traffic lights within the captured image. The detected region is subsequently analysed in

the HSV colour space to determine whether the illuminated signal is red,

## yellow, or green. By combining deep-learning-based object localization with conventional colour segmentation, the system achieves reliable traffic light

## recognition while reducing the computational complexity associated with

directly classifying the entire image.

To maintain real-time performance, image acquisition and image processing are executed independently. The image subscriber stores only the newest received frame, while a dedicated worker thread continuously processes the latest available image. When image processing temporarily becomes slower than the camera frame rate, intermediate frames are discarded instead of queued, ensuring that the perception system always reacts to the most recent

scene rather than progressively increasing system latency.

The outputs of the QR code detector and traffic light detector are combined into a single vision status message that is published whenever either detection state changes. To improve robustness against transient misdetections, both detection results are independently debounced before publication, ensuring that only confirmed state changes are propagated to the remainder of the system. When a confirmed transition to a green traffic light is detected, the vision node additionally publishes a notification message to the designated receiver topic used during the competition. A separate LED indicator node subscribes to the vision status topic and controls two GPIO-connected LEDs to provide immediate visual feedback indicating whether a QR code has been

successfully detected.

The modular software architecture enables perception, communication, and actuator control to operate independently while exchanging information through standardized ROS2 topics. This separation of responsibilities improves software maintainability, facilitates debugging, and allows additional autonomous functions to be integrated into the system with minimal

modification to the existing control framework.

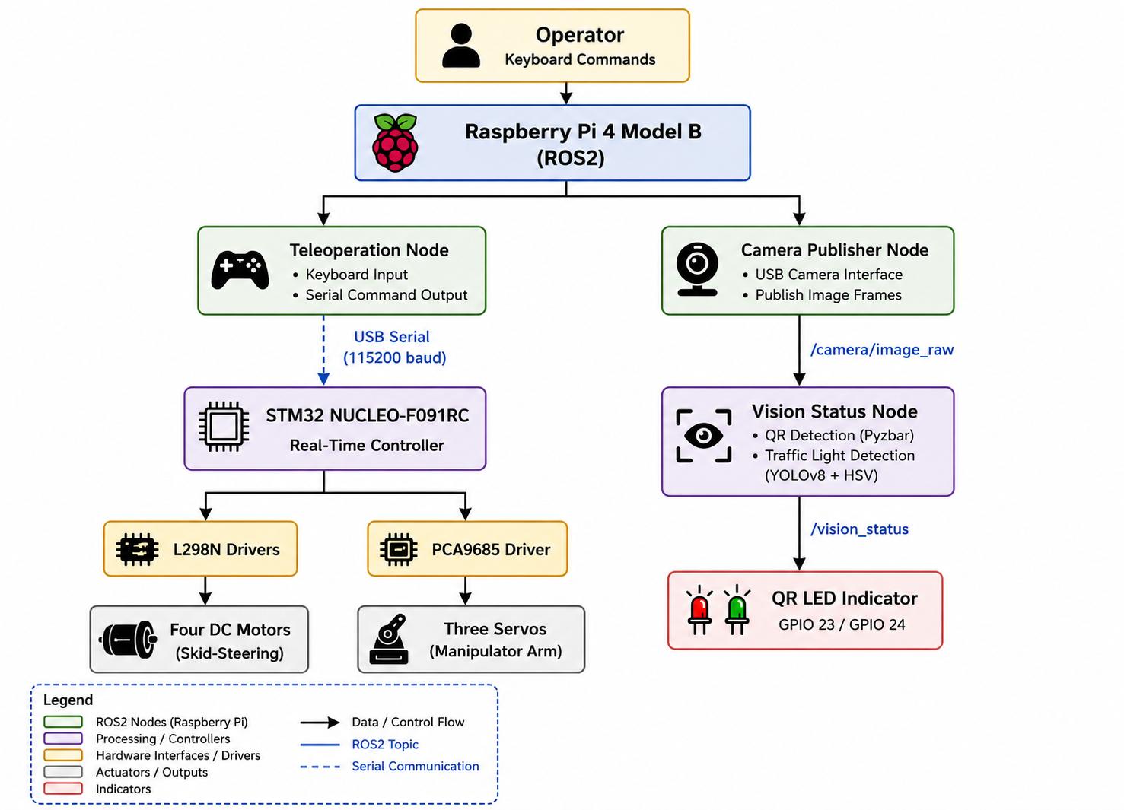
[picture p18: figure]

Figure VII. Overall software architecture of the ELIBot control and vision system.

# 3.Operating Instructions

After assembling the robot that is placing the motors and circuit in their designated positions and attaching both the inner and outer wheels in the correct orientation, we can proceed with the software setup.

First, we connect the microcontroller to the Raspberry Pi 4 and power the Raspberry Pi 4 using the power bank. Once the Raspberry Pi is powered, we connect it via HDMI to a computer and use OBS Studio to view the Raspberry Pi's environment on the computer screen. From there, we can open a terminal and begin running the required nodes.

Four nodes are required to control ELIBot:

1. The first node uses the on-robot camera to capture RGB frames and publishes this data to the topic /camera/image_raw.
2. The second node subscribes to this topic to retrieve the RGB stream and detect the presence of a QR code, a traffic light, and the current light status displayed by the traffic light. This node only publishes a message when there is a change from the previous state, sending it to a second topic called /vision_status.
3. The third node subscribes to the vision status topic and controls the external LED indicators according to the QR code detection result. The traffic-light notification message is published directly by the vision status node when a confirmed transition to a green signal is detected.
4. The final node captures keyboard input and forwards the corresponding control commands to the STM32 microcontroller, which performs the real-time control of the four DC motors and three servo motors while publishing actuator feedback to ROS2.

Once all nodes are running, we disconnect the laptop from the Raspberry Pi and connect the LiPo battery to check that all motor drivers are powered, and to confirm that we can control the robot by moving the wheels and manipulator arm.

# 4. References

[1] R. Sell, G. Aryassov, A. Petritshenko, and M. Kaeeli, “Kinematics and dynamics of configurable wheel-leg,” in Proc. 8th Int. DAAAM Baltic Conf. Industrial Engineering
[2] C. Zheng and K. Lee, “Wheeler: Wheel-leg reconfigurable mechanism with passive gears for mobile robot applications,” in Proc. IEEE Int. Conf. Robotics and Automation (ICRA),

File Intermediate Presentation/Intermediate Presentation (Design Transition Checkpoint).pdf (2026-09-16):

### TEAM 12 INTERMEDIATE PRESENTATION

Abdullah Al Ayaat
G. C. Mohnish
BURTENSHAW Catherine Ella
TAN Daphne Jillian Gan
ZAHID Muhammad Abdullah

J U N E 1 9 , 2 0 2 6

# PRESENTATION AGENDA

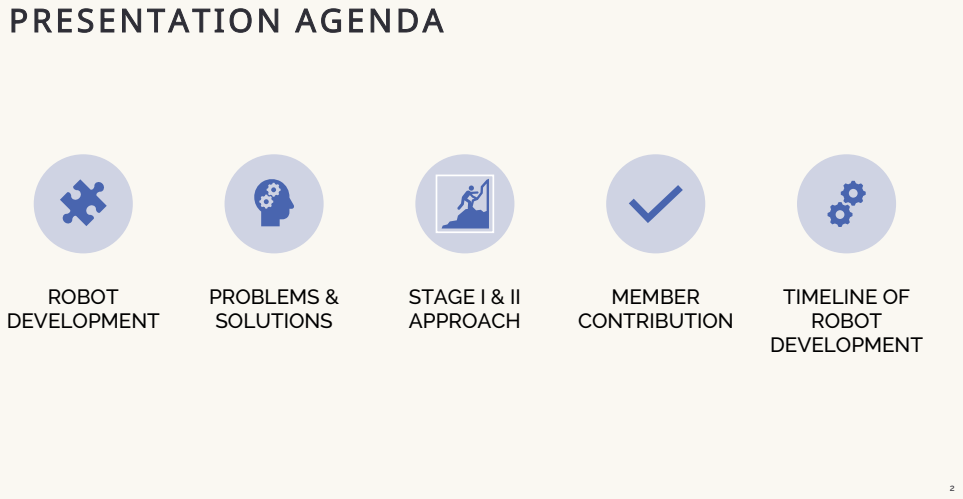
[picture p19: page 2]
ROBOT DEVELOPMENT; PROBLEMS & SOLUTIONS; STAGE I & II APPROACH; MEMBER CONTRIBUTION; TIMELINE OF ROBOT DEVELOPMENT

# Robot Development

Tri-Wheel Robot | Four-Wheel Robot

T E A M 1 2 | 3

# Stability issue due to tri-wheel design

# ROBOT DEVELOPMENT (B OD Y: D ES I GN)

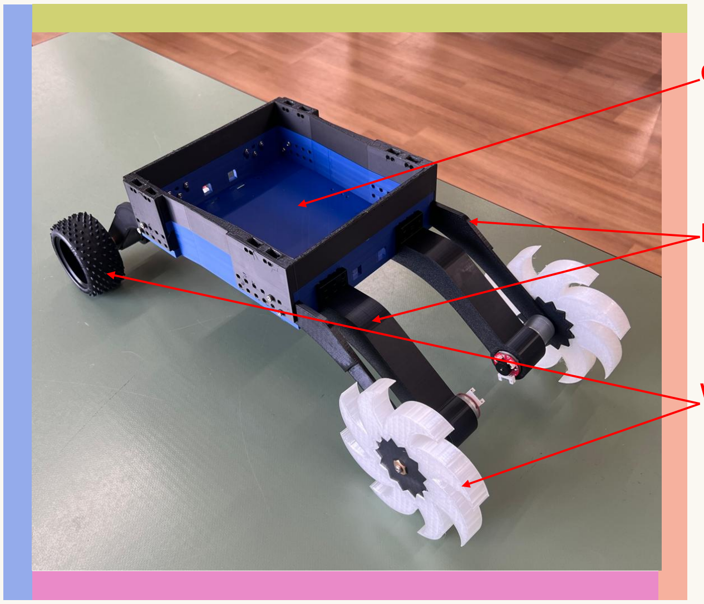
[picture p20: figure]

## Chassis o Fourth Draft completed and printed o Redesigned for improved

## component integration Brackets o Front and rear wheel brackets designed and printed - Fit and mounting tests performed

Wheels + Attachments o TPU front wheel prototypes printed o Flexible wheel design developed o Attachment compatibility verified

T E A M 1 2

# Robot Development : Chassis

# - Early drafts suffered from a base that

was too thin.

# - The second draft had dimensions too small to accommodate all components

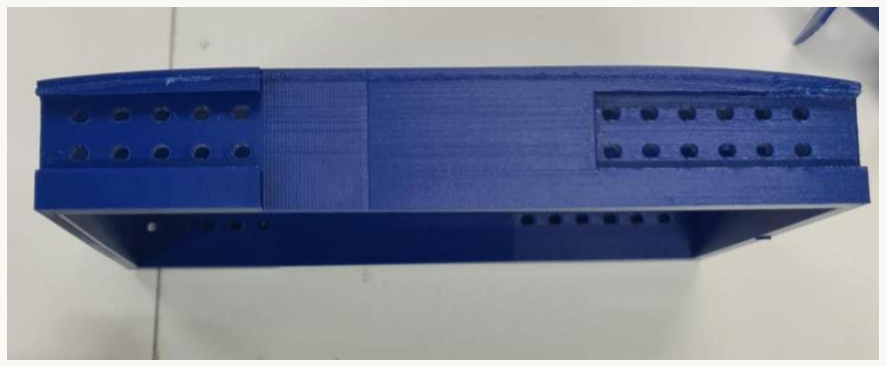
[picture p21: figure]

# - The third draft experienced warping due to incorrect slicer settings and

poor bed adhesion.

# 3rd Draft

# Robot Development : Brackets

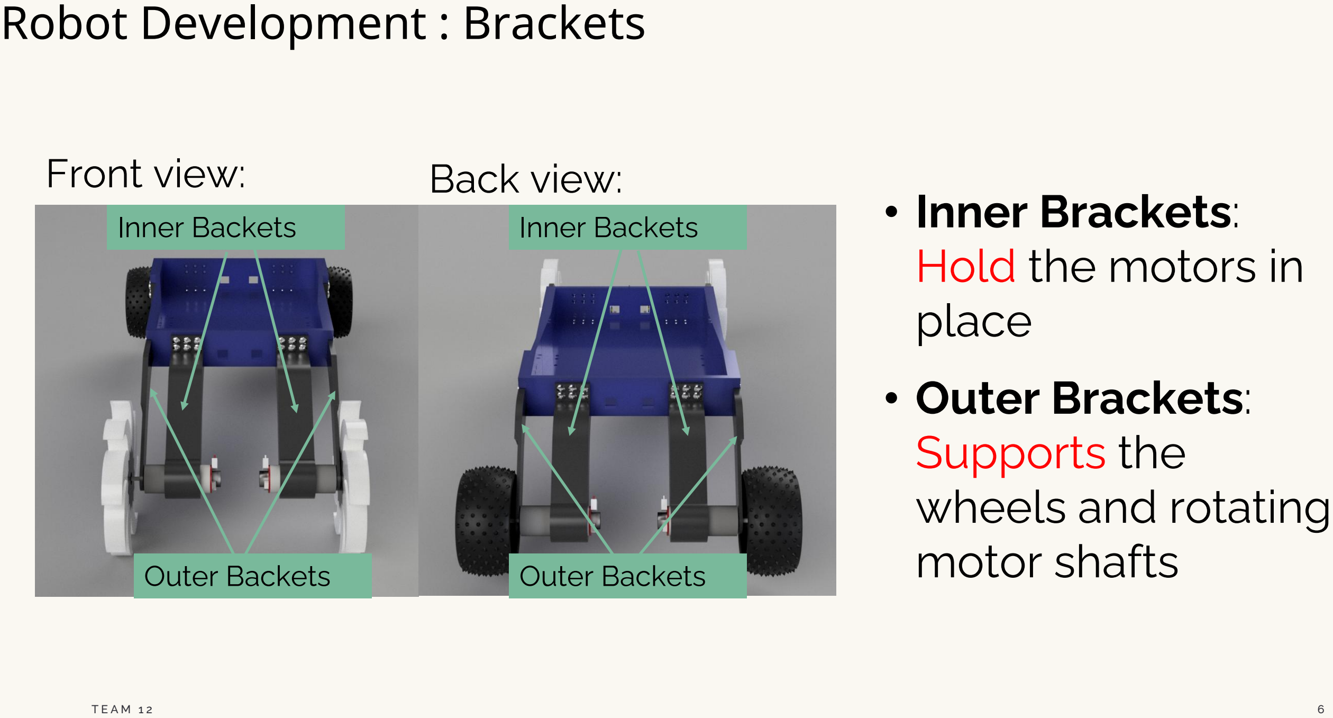
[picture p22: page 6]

## - Inner Brackets: Hold the motors in place - Outer Brackets: Supports the wheels and rotating motor shafts

Front view: | Back view:
Inner Backets | Inner Backets
Outer Backets | Outer Backets

# Robot Development :Wheels + Attachments

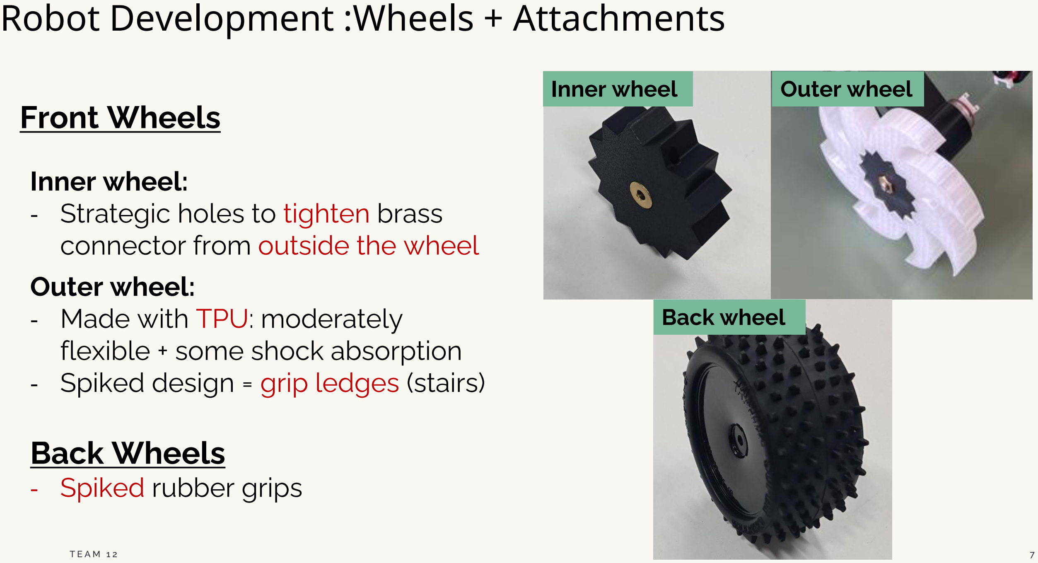
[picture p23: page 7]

Inner wheel:
- Strategic holes to tighten brass connector from outside the wheel Outer wheel:
- Made with TPU: moderately flexible + some shock absorption
- Spiked design = grip ledges (stairs)

Front Wheels

Back Wheels
- Spiked rubber grips
Inner wheel | Outer wheel

Back wheel

# I S S U E S & S O L U T I O N S

# ROBOT PROGRESS (BODY: MECHANICAL)

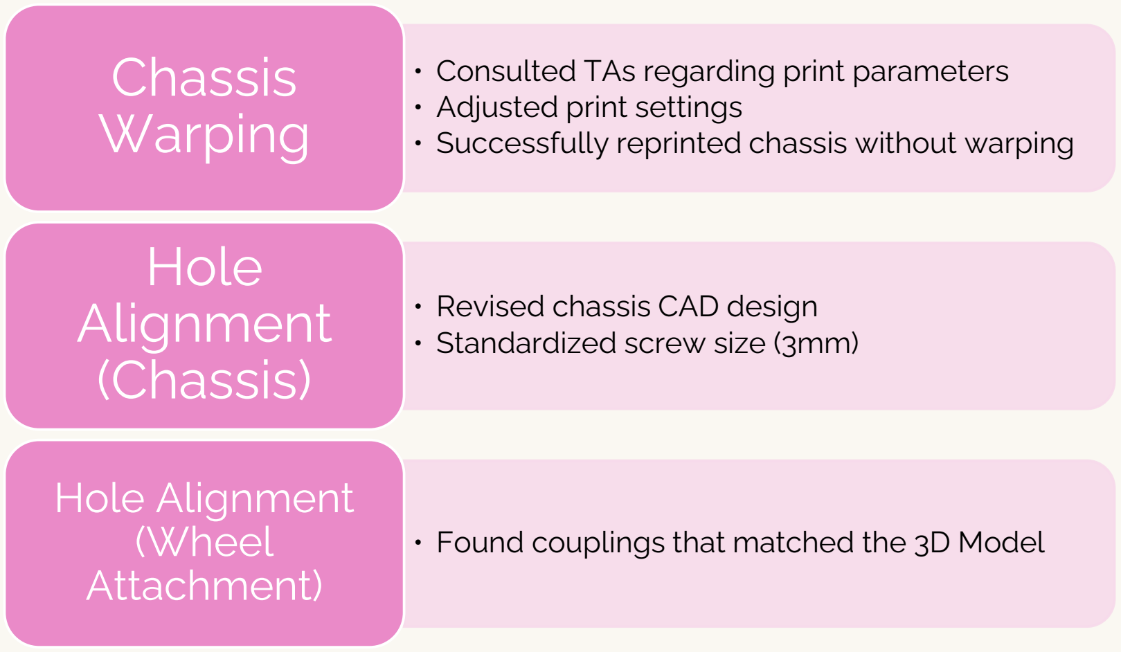
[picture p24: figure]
• Adjusted print settings; Chassis Warping; • Revised chassis CAD design • Standardized screw size (3mm); Hole Alignment (Chassis); Hole Alignment (Wheel Attachment)

- Consulted TAs regarding print parameters
- Successfully reprinted chassis without warping

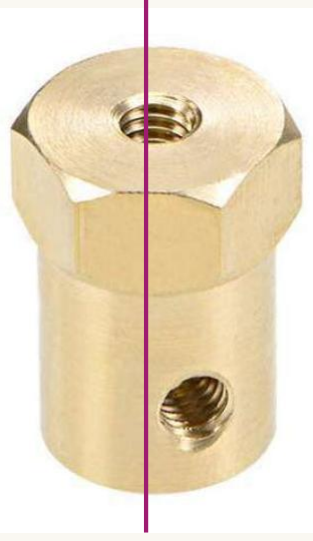
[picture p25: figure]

- Found couplings that matched the 3D Model

## Robot Development (internal components)

LIPO BATTERY 12V

Power Bank

Raspberry pi 4

Buck Converter

T E A M 1 2

# Robot Development (internal components)

LIPO BATTERY 12V

Power Bank

POWER CIRCUIRT

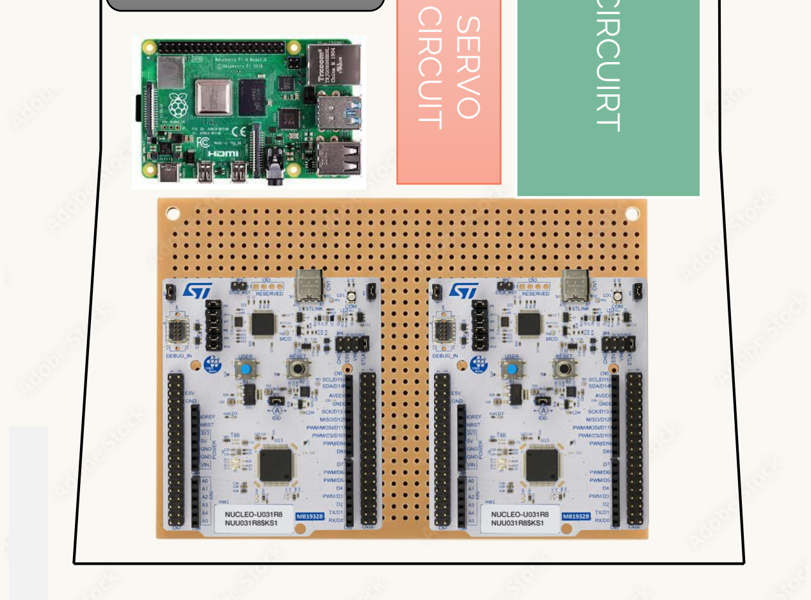
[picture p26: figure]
CIRCUIT; SERVO

T E A M 1 2

# ROBOT PROGRESS (GEARED MOTOR CIRCUIT )

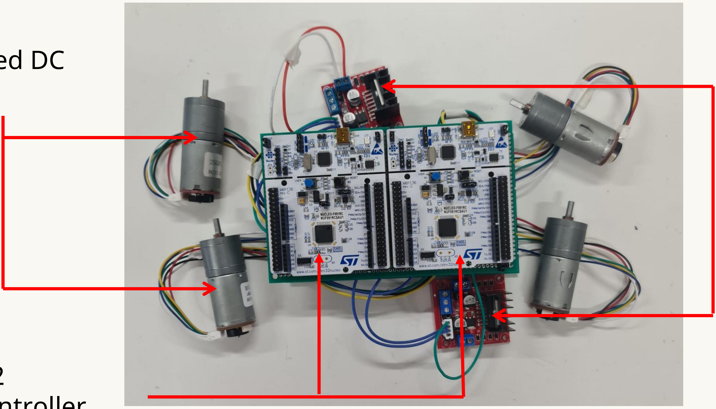
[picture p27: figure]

# 4-Geared DC Motor

2 –L298N

# Motor Drivers

# 2-STM32 Microcontroller

# ROBOT PROGRESS (GEARED MOTOR CIRCUIT )

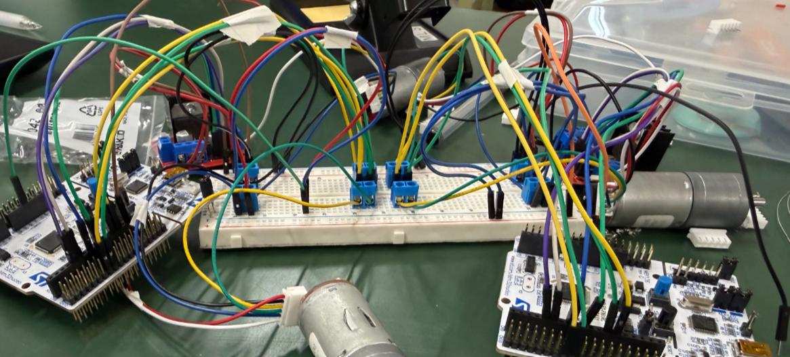
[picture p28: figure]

# - We built a test breadboard circuit to write and test our code, as well as validate our design

# - We moved to a perf-board for stronger connections and a more compact design to fit inside the robot

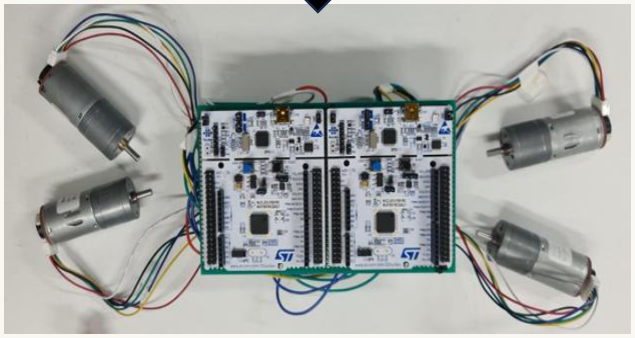
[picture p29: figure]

# ROBOT PROGRESS (BODY: CODING)

# Accomplished:

- Communication between server and raspberry pi.

# - Grounding Dino on the server for open-vocabulary object detection – allowing detection

of:

# - The doorknob

# - QR Code Cardboard

# - Red Cube Object

# - Program for black line detection and motion

command JSONs.

# - Program for controlling four motors

independently.

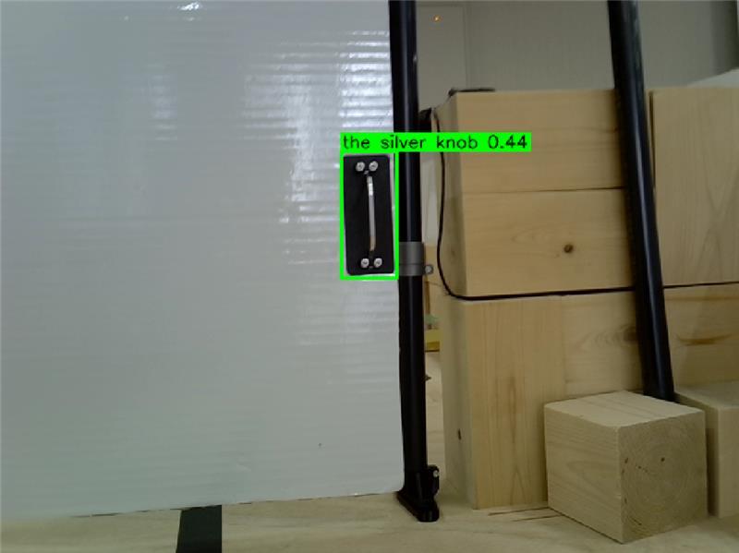
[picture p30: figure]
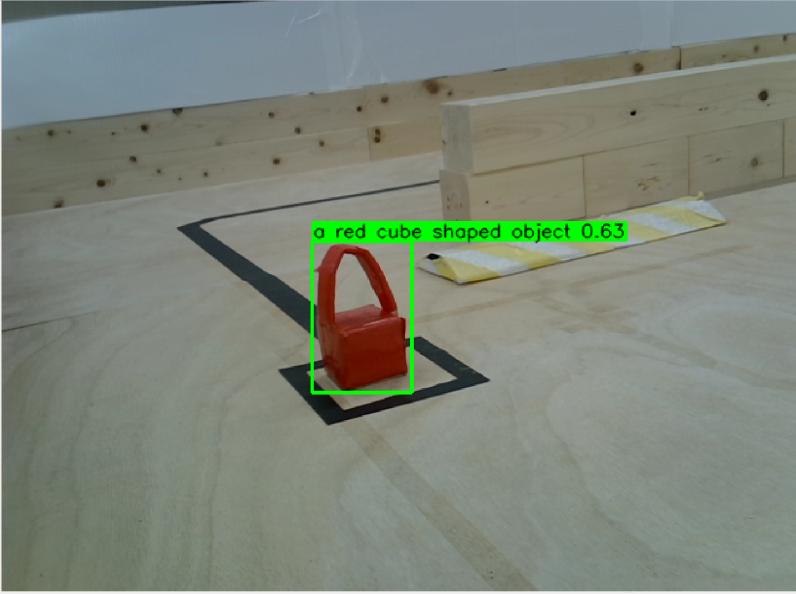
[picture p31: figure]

# ROBOT PROGRESS (MANIPULATOR DESIGN)

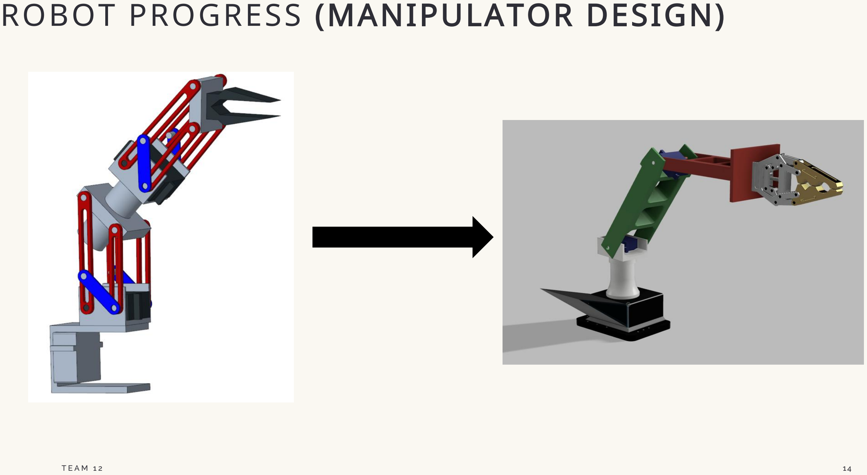
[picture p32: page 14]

ROBOT PROGRESS
(MANIPULATOR: DESIGN)

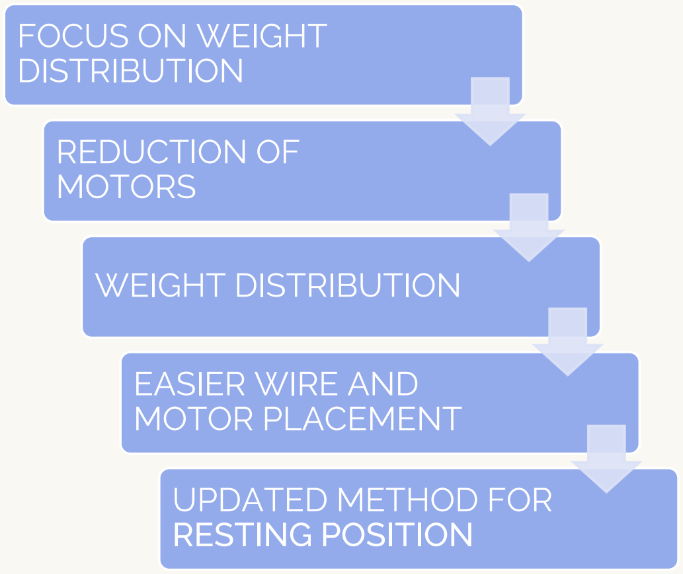
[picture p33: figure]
FOCUS ON WEIGHT DISTRIBUTION; REDUCTION OF MOTORS; WEIGHT DISTRIBUTION; EASIER WIRE AND MOTOR PLACEMENT; UPDATED METHOD FOR RESTING POSITION
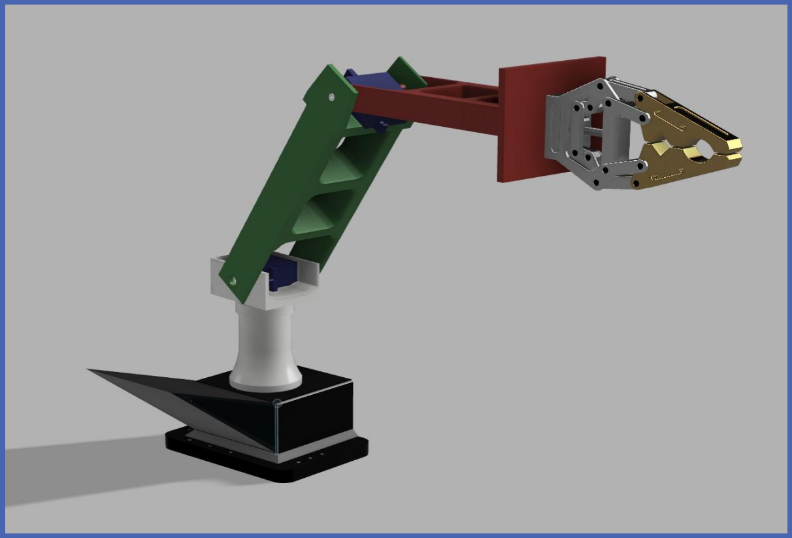
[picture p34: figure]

## ROBOT PROGRESS (MANIPULATOR)


# - The 3R-manipulator consists of 3 servo motors that provide us with 3DoF

# - With the help of a solenoid actuator, we can open and close the pincher of the manipulator

CURRENT PROBLEMS(+ POSSIBLE SOLUTIONS)

- Large Robot Footprint/Insufficient Torque
Limits turning capability in confined areas.
We require stronger motors for over coming the stairs and turning


- Solution:
Reduce central compartment length. Stack electronics vertically.
Move brackets beneath the chassis to decrease footprint.
Calculate the exact torque required due to design change

CURRENT PROBLEMS(+ POSSIBLE SOLUTIONS)

- 4-Motor Control Integration
Difficulty controlling four motors with a single or double
microcontroller.
- Solution:
Continue hardware and software debugging.
Validate motor communication and control reliability.

- Manipulator Pincher
The pincher mechanism proved too stiff or rigid for the solenoid actuator
to produce sufficient force to engage and grip the door


- Solution:
Incorporate a rigid-flexible hybrid design with compliant hinges to reduce pincher stiffness and improve actuation.

CURRENT PROBLEMS(+ POSSIBLE SOLUTIONS)

- System Integration & Tuning Individual modules are developed but not fully tested together.
- Next Steps:
Integrate all subsystems.
Fine-tune control algorithms on the complete robot.

CURRENT PROBLEMS(+ POSSIBLE SOLUTIONS)

MECHANICS; ELECTRONICS

PROGRAMMING

# Approach for Stage-I

# The robot will push the door

# Robot design with back wheel

# 3D printed claw wheel Scanning using camera

# 3D printed claw


# wheel Robot design with back wheel Using camera 2R manipulator with


# Solenoid-Driven Pincher

# Approach for Stage-II

# The door must be opened not pushed


The QR code
must be
flipped

# The Block must be picked

# Approach for Stage-II


24

M E M B E R C O N T R I B U T I O N

Abdullah :
- Setting up Grounding Dino
- Developing line detection algorithm
- Setup up key based control for robot motors

Mohnish :
- Initial manipulator arm design
- Initial manipulator 3D Printing
- Electrical circuit design
- Circuit assembly and testing

Daphne :
- Rear bracket initial design
- Component research
- MWS 3D Printing
- Ordering & machine booking

Cat :
- Main Robot Body CAD Design
- Wheel (+ attachments) Design
- MWS 3D Printing
- Recent Bracket CAD Design

Ayaat :
- Main Body concept design
- Front Bracket initial Design
- Perf-board soldering
- Designing and Completing the final manipulator arm

T E A M 1 2

P R O J E C T T I M E L I N E

25

| WEEK
TASK | 7 | 8 | 9 | 10 | 11 | 12 | 13 | 14 | 15
| 5/26 | 5/29 | 6/2 | 6/5 | 6/9 | 6/12 | 6/16 | 6/19 | 6/23 | 6/26 | 6/30 | 7/3 | 7/7 | 7/10 | 7/14 | 7/17 | 7/24
Design development

Parts manufacturing

Prototyping

Further development

Preparation and test runs

Presentation

T E A M 1 2

T H A N K Y O U : )

Q & A

T E A M 1 2

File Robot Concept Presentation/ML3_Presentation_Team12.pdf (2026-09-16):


# ML3 PROJECT PRESENTATION

## TEAM 12:

Mohnish, Abdullah, Daphne, Catherine and Ayaat

1


## Robot Concept : (Tri-wheel)

The Tri-wheel can be divided into 3 separate parts
- Front Half
- Rear Half
- Top Half

2


Front Half Spring Mechanism:
- The suspension helps
reduce stress on the
front wheel
- Assist with the drop
- The front wheel is the
main driving force of the


robot | REF:

3

## Front Half


Configurable wheel that has two forms closed and open
configurations

With the help of a gears, we can dynamically switch between the two configurations

4

[1] R. Sell, G. Aryassov, A. Petritshenko, and M. Kaeeli, “Kinematics and dynamics of configurable wheel-leg,” in Proc. 8th Int. DAAAM Baltic Conf. Industrial Engineering
[2] C. Zheng and K. Lee, “Wheeler: Wheel-leg reconfigurable mechanism with passive gears for mobile robot applications,” in Proc. IEEE Int. Conf. Robotics and Automation (ICRA),

[1]

[2]

## Front Half

IDEA1; IDEA 2


Rear Half
The Rear half consists of two generic wheels that are
connected to a 4-bar spring

## Top Half


The 2R-manipulator consists of 2 servo motors that provide us with1DoF in the forward direction

Servo Motor

7

### Top Half


8

Solenoid-Driven
Pincher
- With the help of a solenoid actuator, we can open and close the pincher of the manipulator

[3]“Solenoid-Driven Pincher,” YouTube. [Online]. Available: https://www.youtube.com/watch?v=HrPFWirsb54. [Accessed: May 20, 2026].

Originality • The use of a Tri

-wheel design to
be able to overcome the ditch as well as the ledge.
- Incorporate a configurable wheel

-leg to aid in stair
climbing.
- Implementation of spring
based support to act as
suspension for uneven terrain


9

Motivation

10

- To further develop engineering and fabrication skills
- To gain hands-on experience working with all-terrain robotic platforms
- To understand how robotic design can help overcome challenging obstacles

### Approach for Stage-I

Configurable Wheel Spring suspension at the back wheel; Using camera 2R manipulator with Solenoid-Driven Pincher

The robot will push
the door

Spring suspension at
the back wheel

Configurable Wheel
Scanning using
camera


11

12

### Approach for Stage-I (Configurable Wheel )

Closed Configuration | Open Configuration


- Functional in smooth terrain
- Enables us to overcome the bump and slope (obstacle 2 and 6 respectively )


- Functional in uneven terrain
- Enables us to overcome the ditch, roller and stairs (obstacle 4, 7, and 8 respectively )
[1] [1]

Approach for Stage-I 2R Manipulator

- The 2R manipulator will be able
to push
- Solenoid-Driven Pincher will enable us to pick up the block


13

14

### Approach for Stage-II


The door must be
opened not pushed


The QR code
must be flipped


The Block must
be picked

### Approach for Stage-II


15

### Approach for Stage-II

1

2

3

4

5

6

Detect door knob (YOLO + OpenCV) Align gripper to knob in image space
Advance in small steps, re-verify each time Proximity sensor halts forward motion
Close gripper — contact sensor confirms grasp Pull knob — camera verifies door moved

RGB Camera detects
knob & gripper


Contact Switch confirms
successful grip on knob

Visual Servoing minimizes
image-space position error

Proximity Sensor triggers
grasp sequence precisely

Approach for Obstacle 1 (Door Opening)

16

### Approach for Stage-II

Approach for Obstacle 5 (QR Code)
- Detect red cardboard using RGB camera
- Move end-effector toward the side of the cardboard using the same manipulation strategy as Obstacle 1
- Push and rotate the cardboard
- Scan the QR code using the onboard camera

17


### Approach for Stage-II

Approach for Obstacle 10 (Block Picking)
- Use teleoperation control for robot and manipulator movement
- Stream live camera feed from the robot to the control station
- Operator visually guides the manipulator to align with and grasp the block
- Carry the block safely to the target location


18

### Role Assignment


Robot Design and Fabrication- All Members

Software and Control – Abdullah, Mohnish

Circuit making – Ayaat, Catherine, Daphne

Scheduling, E-Portal, and Progress Tracking - Daphne

### List of Components and Estimated Budget

No. | Component | Quantity | Use | Price
1 | Servo Motor | 4 | Arm/Locomotion | IN box
2 | BLDC Motor | 3 | Locomotion | IN box
3 | Motor driver | 4 | Control | IN box
4 | Wheels | 3 | Locomotion | Printable
5 | 3D Filament | 2 | Body | ¥5,000
6 | Screws | TBD | Whole robot | ¥2,000
7 | Solenoid-actuator | 1 | Pincher | ¥1,500
8 | Suspension Mechanism | 1 | For the front wheel | ¥1500
Total | ¥10,000 | 20

### Timeline for Robot Development

| WEEK
TASK | 7 | 8 | 9 | 10 | 11 | 12 | 13 | 14 | 15
| 5/26 | 5/29 | 6/2 | 6/5 | 6/9 | 6/12 | 6/16 | 6/19 | 6/23 | 6/26 | 6/30 | 7/3 | 7/7 | 7/10 | 7/14 | 7/17 | 7/24
Design development

Parts manufacturing

Prototyping

Further development

Preparation and test runs

Presentation

21

### Thank You

Q&A

22

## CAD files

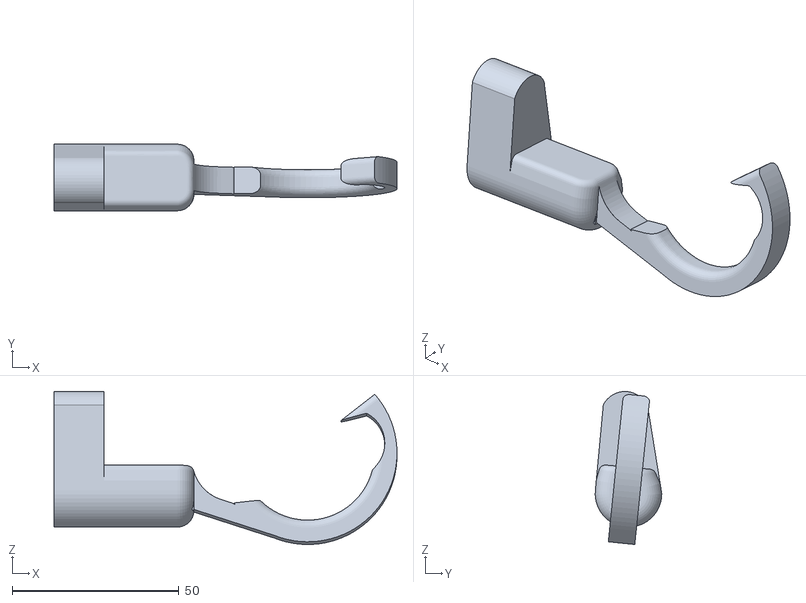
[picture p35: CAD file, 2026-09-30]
STL Files/Manipulator Parts/Manipulator Hook.stl
103.0 x 20.0 x 45.9

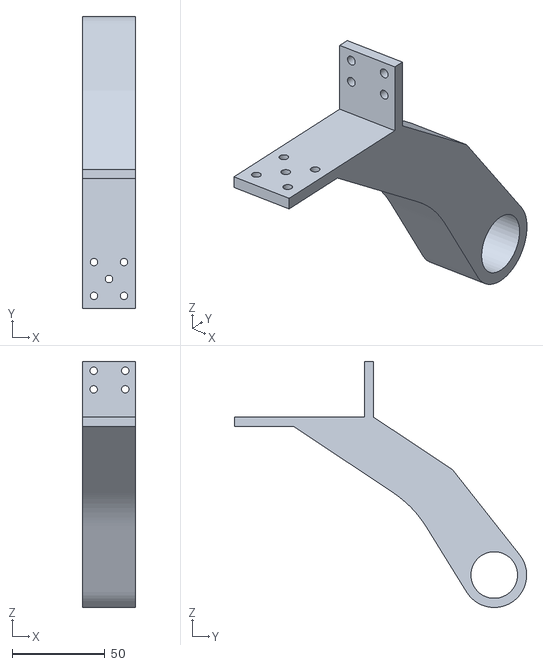
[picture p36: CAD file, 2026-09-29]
STL Files/Robot Body/Rear-Right Bracket.stl
28.5 x 157.5 x 132.5

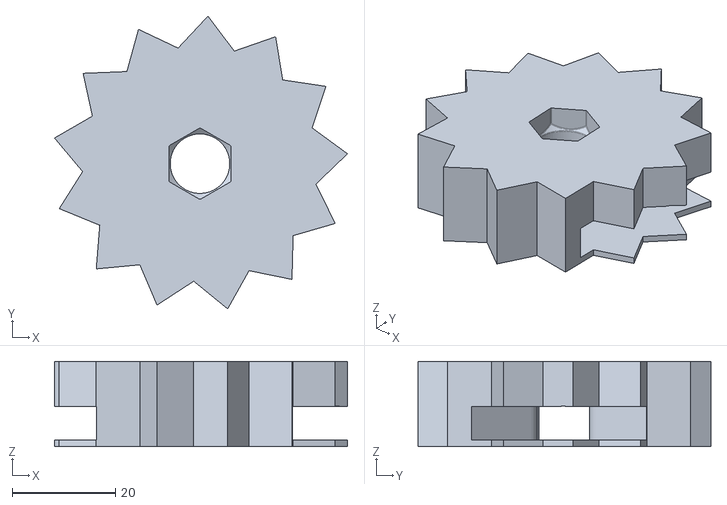
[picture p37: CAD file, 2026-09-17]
STL Files/Robot Wheels/Inner Part of the Wheel (PLA).stl
56.6 x 56.6 x 16.5

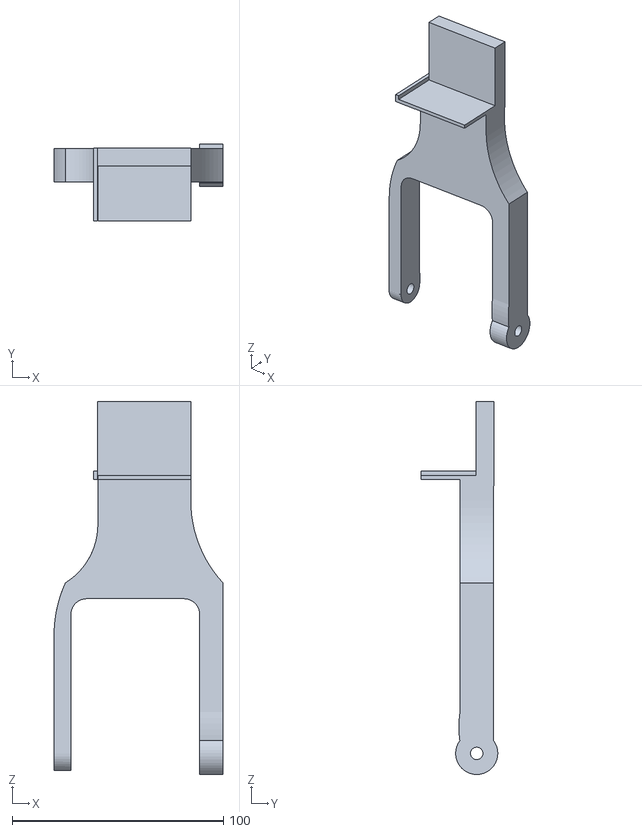
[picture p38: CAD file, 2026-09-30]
STL Files/Manipulator Parts/Manipulator Top Part.stl
80.0 x 36.3 x 176.6

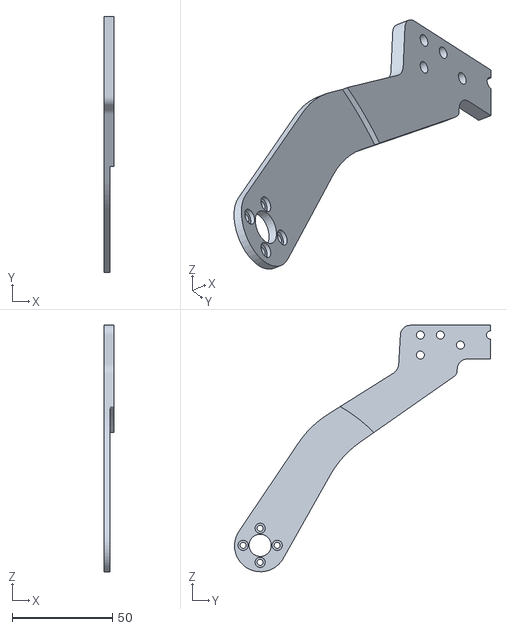
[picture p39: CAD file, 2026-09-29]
STL Files/Robot Body/Front-Left Support Bracket.stl
5.00 x 127.8 x 123.1

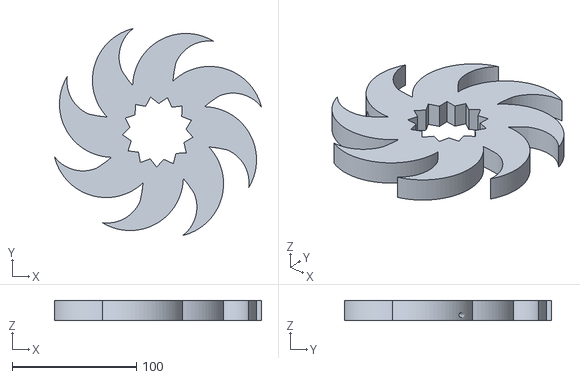
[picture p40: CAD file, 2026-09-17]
STL Files/Robot Wheels/Outer Wheel (TPU).stl
166.9 x 166.9 x 16.5

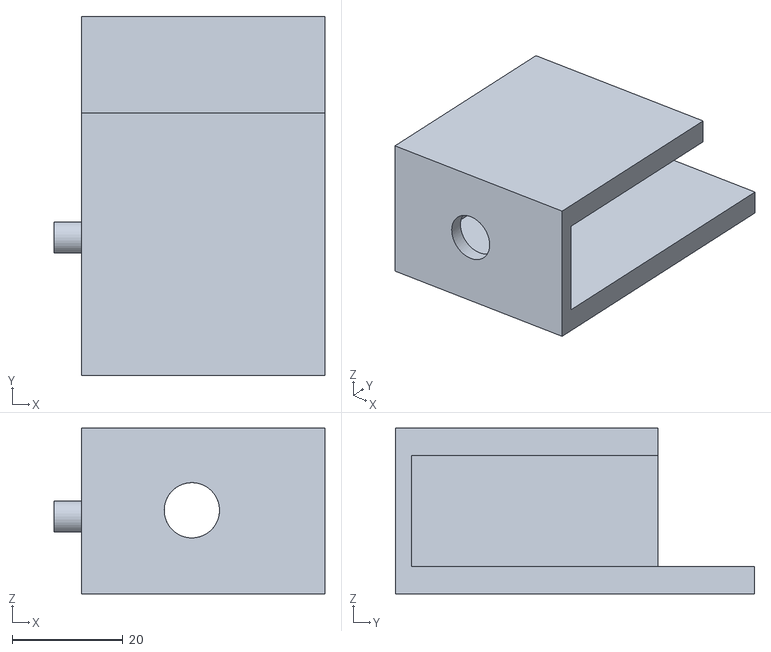
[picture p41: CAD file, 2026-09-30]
STL Files/Manipulator Parts/Manipulator Base Part.stl
49.0 x 65.0 x 30.0

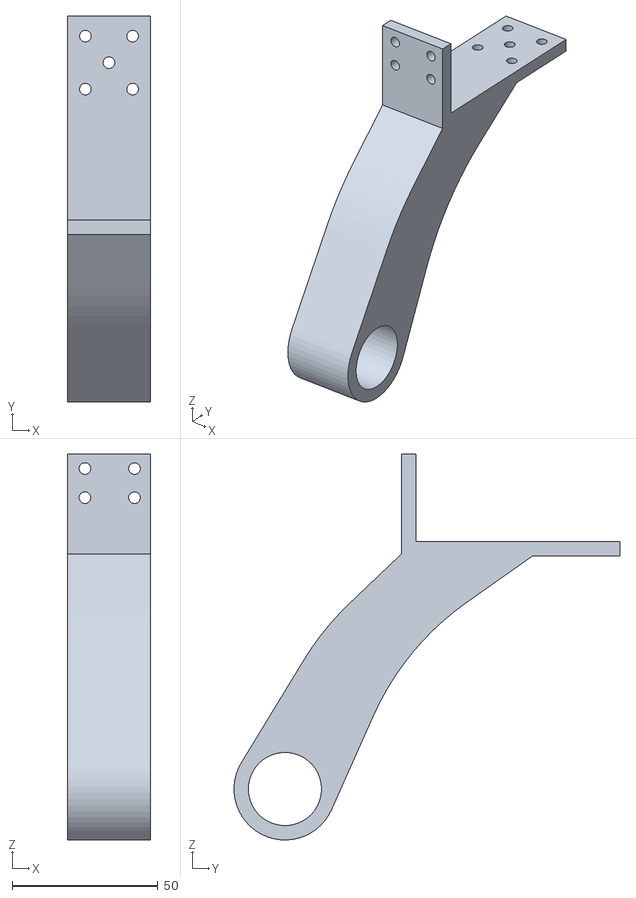
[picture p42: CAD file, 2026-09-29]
STL Files/Robot Body/Front-Right Bracket.stl
28.5 x 132.5 x 132.5

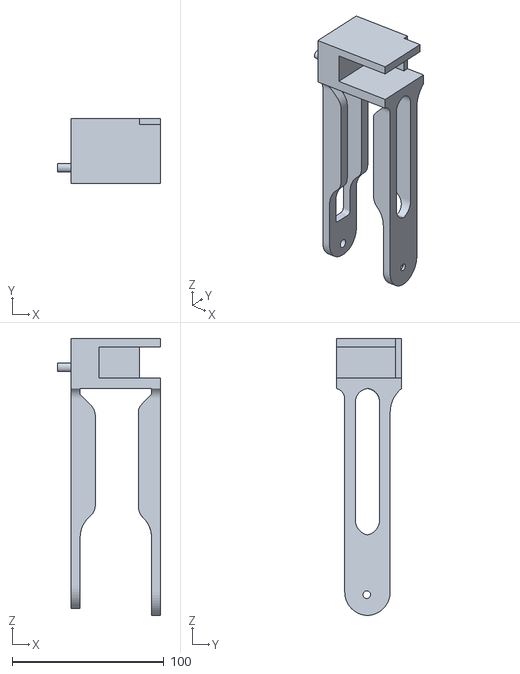
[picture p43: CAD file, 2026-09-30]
STL Files/Manipulator Parts/Manipulator Middle Part.stl
68.0 x 43.0 x 182.7

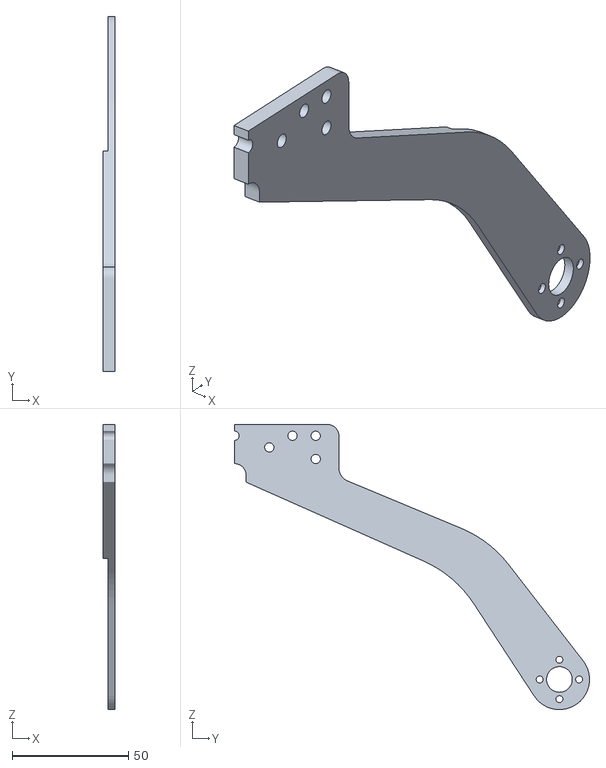
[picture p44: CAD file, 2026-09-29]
STL Files/Robot Body/Rear-Right Support Bracket.stl
5.00 x 153.0 x 122.9

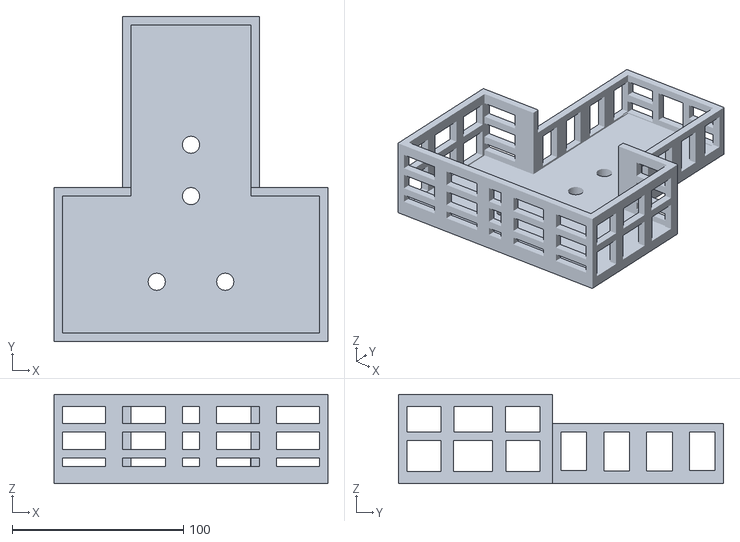
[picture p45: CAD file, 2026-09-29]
STL Files/Robot Body/Cage.stl
160.0 x 190.0 x 52.0

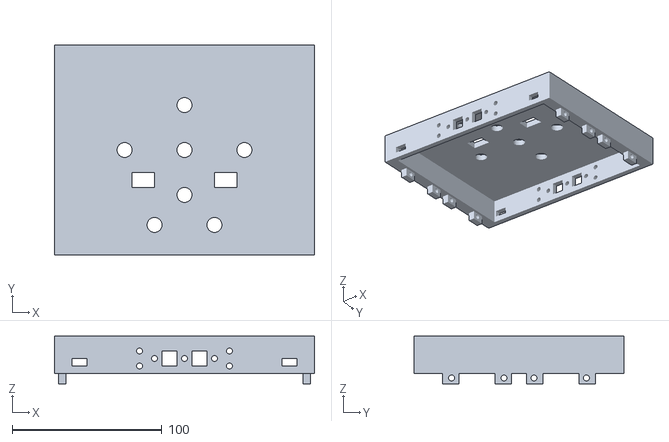
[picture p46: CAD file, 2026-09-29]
STL Files/Robot Body/Top Chassis.stl
173.5 x 140.0 x 32.0

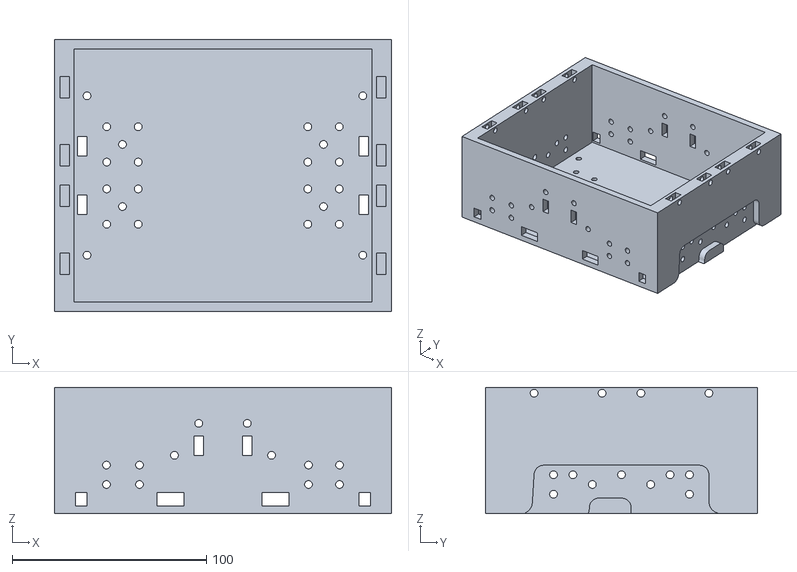
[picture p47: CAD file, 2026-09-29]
STL Files/Robot Body/Bottom Chassis.stl
173.5 x 140.0 x 65.0

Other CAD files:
STL Files/Robot Body/Front-Right Support Bracket.stl
STL Files/Robot Body/Rear-Left Bracket.stl
STL Files/Robot Body/Front-Left Bracket.stl
STL Files/Robot Body/Rear-Left Support Bracket.stl

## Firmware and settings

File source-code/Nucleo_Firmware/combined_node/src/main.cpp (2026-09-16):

// =============================================================
//  Combined node: 4x open-loop PWM DC motors + RC servos on a
//  PCA9685 16-channel I2C PWM driver, all commanded over one
//  serial link.
//
//  Motor control is taken verbatim from mbed_node — unchanged.
//
//  Servos are driven by a PCA9685 board over I2C instead of
//  bit-banged GPIO (SoftServo). WIRING:
//    Nucleo D14 (SDA, PB_9) -> PCA9685 SDA
//    Nucleo D15 (SCL, PB_8) -> PCA9685 SCL
//    Nucleo 3V3             -> PCA9685 VCC  (logic power only)
//    Nucleo GND             -> PCA9685 GND  <-- MUST be common with servo supply
//    5-6V supply +/-        -> PCA9685 V+/GND (separate servo power rail)
//  Do NOT power servos from the Nucleo 5V pin — a stalled servo can pull
//  several hundred mA and brown out the board. V+ and VCC are separate
//  rails; never bridge them (12V on VCC kills the chip).
//  This frees PB_9/PB_8/PB_11/PA_7, previously used as individual
//  SoftServo GPIO pins — PB_9/PB_8 now carry the I2C bus, PB_11/PA_7
//  are unused.
//
//  Serial command: the Pi forwards raw, single-byte keypresses — no
//  framing or terminator, one byte is one command. This firmware (not
//  the Pi) owns all interpretation now:
//    w a s d q         -> motor direction, scaled by the current speed level
//    0-9               -> select motor speed, 10%-100%
//    u j i k o l p ;   -> nudge servo 1-4 by +-SERVO_STEP degrees
//    c                 -> center all servos
//  Motors are hold-to-move: if no w/a/s/d/q byte arrives within
//  HOLD_TIMEOUT, they're stopped automatically (deadman watchdog —
//  this used to live in the Pi script, now lives here since the Pi
//  only forwards raw keys and no longer tracks timing itself). Servos
//  hold their last commanded angle instead — no watchdog.
//
//  Feedback: comma-separated echo of all setpoints on one line,
//  duties first, then servo angles, e.g.
//      0.50,-0.50,0.00,1.00,90.0,-45.0,0.0,135.0
//  (unchanged — still consumed by the Pi for ROS2 topic telemetry)
// =============================================================
#define NUM_MOTORS 4
#define NUM_SERVOS 3

#include "mbed.h"
#include "SerialROS2.hpp"
#include "PWMMotor.hpp"
#include "PCA9685.hpp"
#include <cstdio>

// ---------------- motors (identical to mbed_node) ----------------

// Pin pairs {forward_pin, backward_pin} for each motor slot.
static const PinName MOTOR_PINS[4][2] = {
    {PA_8, PA_9},   // Motor 1
    {PC_6, PC_7},   // Motor 2 //PB_15
    {PB_14_ALT0, PB_15_ALT1},  // Motor 3  <-- set your pins here
    {PA_4, PA_6_ALT0},   // Motor 4  <-- set your pins here
};

PWMMotor* motors[NUM_MOTORS];
float     duties[NUM_MOTORS] = {};

// ---------------- servos (PCA9685 over I2C) ----------------

// Sized to 4 regardless of NUM_SERVOS (same pattern as MOTOR_PINS above):
// only the first NUM_SERVOS entries are used, so NUM_SERVOS can be set to
// 1-4 without touching these tables.
static_assert(NUM_SERVOS >= 1 && NUM_SERVOS <= 4, "NUM_SERVOS must be 1-4, or add more entries to SERVO_CH/PULSE_*_US/servo_range below");

// NOTE: named PCA_SDA/PCA_SCL, not I2C_SDA/I2C_SCL — mbed's HAL headers
// already #define I2C_SDA/I2C_SCL (Arduino-shield pin aliases), and reusing
// those names here gets silently macro-expanded into the wrong declaration.
static const PinName PCA_SDA  = D14;   // PB_9
static const PinName PCA_SCL  = D15;   // PB_8
static const uint8_t PCA_ADDR = 0x40;  // bump if you bridged the A0..A5 jumpers
static const float   SERVO_FREQ = 50.0f;   // Hz — standard hobby servo frame

// Which PCA9685 output channel (0-15) each servo is plugged into.
static const uint8_t SERVO_CH[4] = { 0, 1, 2, 3 };

// Per-servo pulse-width calibration, in microseconds, at full deflection.
// 500-2500us is the usual full range, but every servo differs — widen
// gradually and STOP before the servo grinds against its physical end
// stop, or you will strip the gears.
static const float PULSE_MIN_US[4] = { 500.0f, 500.0f, 500.0f, 500.0f };
static const float PULSE_MAX_US[4] = { 2500.0f, 2500.0f, 2500.0f, 2500.0f };

// notes: range from center to min/max, in degrees.
// int servo_range[4] = {90, 90, 90, 90};     // DS3225
int servo_range[4] = {90, 90, 90, 90};    // 8125MG

PCA9685 pca(PCA_SDA, PCA_SCL, PCA_ADDR);
float servo_angles[NUM_SERVOS]  = {};   // target angle, nudged by servo keys (centered at 0)
float servo_current[NUM_SERVOS] = {};   // ramped/smoothed angle actually sent to the PCA9685

static const float SERVO_MAX_SPEED = 300.0f;    // deg/s slew limit (same default as before)
static constexpr auto SERVO_FRAME  = 20ms;       // one PWM frame — matches SERVO_FREQ
static constexpr float SERVO_FRAME_S = 0.020f;

// Map a centered angle (-servo_range..+servo_range) to this servo's
// calibrated pulse width and send it over I2C.
void set_servo_angle(int servo, float deg_from_center) {
    if (servo < 0 || servo >= NUM_SERVOS) return;

    float range = (float)servo_range[servo];
    if (deg_from_center < -range) deg_from_center = -range;
    if (deg_from_center >  range) deg_from_center =  range;

    float center_us    = (PULSE_MIN_US[servo] + PULSE_MAX_US[servo]) / 2.0f;
    float half_span_us = (PULSE_MAX_US[servo] - PULSE_MIN_US[servo]) / 2.0f;
    float pulse_us      = center_us + (deg_from_center / range) * half_span_us;

    pca.set_pulse_us(SERVO_CH[servo], pulse_us);
}

// ---------------- serial link ----------------

SerialROS2 pc(USBTX, USBRX, 115200);

DigitalOut led(LED1);   // onboard green user LED — toggles on every recognized keypress

// ---------------- keypress interpretation (moved here from the Pi) ----------------

static const float SPEED_LEVELS[10] = {
    0.1f, 0.2f, 0.3f, 0.4f, 0.5f, 0.6f, 0.7f, 0.8f, 0.9f, 1.0f
};
static const int DEFAULT_SPEED_INDEX = 7;   // '7' -> 0.8

float current_speed = SPEED_LEVELS[DEFAULT_SPEED_INDEX];      // duty magnitude picked by 0-9
float last_motor_signs[NUM_MOTORS] = {0, 0, 0, 0};            // direction template of the last motor key

// Sign template per motor for each recognized movement key.
// Layout: [front-left, front-right, rear-left, rear-right].
struct MotorKeyEntry { char key; float signs[NUM_MOTORS]; };
static const MotorKeyEntry MOTOR_KEYS[] = {
    { 'w', { 1,  1,  1,  1} },
    { 's', {-1, -1, -1, -1} },
    { 'a', {1,  -1, 1,  -1} },
    { 'd', { -1, 1,  -1, 1} },
    { 'q', { 0,  0,  0,  0} },
};
static const int NUM_MOTOR_KEYS = sizeof(MOTOR_KEYS) / sizeof(MOTOR_KEYS[0]);

// Stop the motors if no movement key arrives within this long — the same
// hold-to-move deadman watchdog the Pi used to run, now living here since
// the Pi only forwards raw keys and no longer tracks timing itself.
static constexpr auto HOLD_TIMEOUT = 300ms;
bool moving = false;
Timer cmd_timer;                                 // free-running, started once in main()
std::chrono::microseconds last_cmd_time{0};

void applyMotorSigns(const float* signs) {
    bool any_nonzero = false;
    for (int i = 0; i < NUM_MOTORS; i++) {
        last_motor_signs[i] = signs[i];
        duties[i] = signs[i] * current_speed;
        if (duties[i] != 0.0f) any_nonzero = true;
    }
    last_cmd_time = cmd_timer.elapsed_time();
    moving = any_nonzero;   // 'q' -> all zero -> not moving
}

static const float SERVO_STEP = 2.5f;   // degrees added per keypress / auto-repeat

// Keyboard -> (servo index, direction) for incremental servo moves.
struct ServoKeyEntry { char key; int index; float dir; };
static const ServoKeyEntry SERVO_KEYS[] = {
    { 'u', 0, -1 }, { 'j', 0, +1 },   // servo 1
    { 'i', 1, -1 }, { 'k', 1, +1 },   // servo 2
    { 'o', 2, -1 }, { 'l', 2, +1 },   // servo 3
    { 'p', 3, -1 }, { ';', 3, +1 },   // servo 4
};
static const int NUM_SERVO_KEYS = sizeof(SERVO_KEYS) / sizeof(SERVO_KEYS[0]);
static const char CENTER_KEY = 'c';   // snap all servos back to 0 degrees

// Dispatch one raw byte from the Pi. LED toggles once per recognized key,
// same heartbeat role the old setCommand() callback used to serve.
void handleKey(char key) {
    bool matched = false;

    for (int i = 0; i < NUM_MOTOR_KEYS && !matched; i++) {
        if (MOTOR_KEYS[i].key == key) {
            applyMotorSigns(MOTOR_KEYS[i].signs);
            matched = true;
        }
    }

    if (!matched && key >= '0' && key <= '9') {
        current_speed = SPEED_LEVELS[key - '0'];
        if (moving) {
            // Rescale the motors already in motion immediately, instead of
            // waiting for the next movement keypress.
            for (int i = 0; i < NUM_MOTORS; i++) {
                duties[i] = last_motor_signs[i] * current_speed;
            }
        }
        matched = true;
    }

    if (!matched) {
        for (int i = 0; i < NUM_SERVO_KEYS; i++) {
            if (SERVO_KEYS[i].key == key) {
                int idx = SERVO_KEYS[i].index;
                if (idx < NUM_SERVOS) {
                    float a     = servo_angles[idx] + SERVO_KEYS[i].dir * SERVO_STEP;
                    float range = (float)servo_range[idx];
                    if (a < -range) a = -range;
                    if (a >  range) a =  range;
                    servo_angles[idx] = a;
                }
                matched = true;
                break;
            }
        }
    }

    if (!matched && key == CENTER_KEY) {
        for (int i = 0; i < NUM_SERVOS; i++) servo_angles[i] = 0;
        matched = true;
    }

    if (matched) led = !led;
}

int main() {
    for (int i = 0; i < NUM_MOTORS; i++) {
        motors[i] = new PWMMotor(MOTOR_PINS[i][0], MOTOR_PINS[i][1]);
        motors[i]->init();
    }

    if (!pca.init(SERVO_FREQ)) {
        // No ACK on the I2C bus. Check: SDA/SCL swapped? VCC missing?
        // Wrong address? Common ground absent?
        while (1) {                       // fast blink = I2C failure
            led = !led;
            ThisThread::sleep_for(100ms);
        }
    }
    for (int i = 0; i < NUM_SERVOS; i++) {
        servo_current[i] = 0;
        set_servo_angle(i, 0);   // start centered
        // Stagger each servo's very first pulse. The slew-rate ramp below
        // only smooths CHANGES to an already-moving servo — it can't soften
        // this first command, since every channel is hard "off" (no pulse
        // at all) until now. If a servo isn't already sitting at 0 degrees,
        // it will race there at its own full speed/torque the instant it
        // gets this pulse. Spacing these out stops N servos' worst-case
        // inrush current from lining up on the same instant at boot.
        ThisThread::sleep_for(150ms);
    }

    pc.init();

    char fb[128];

    Timer servo_timer;
    servo_timer.start();
    cmd_timer.start();

    while (1) {
        // Drain all pending bytes so a burst of auto-repeated keys doesn't
        // lag behind — same reasoning the old Pi-side loop used.
        char c;
        while (pc.pc.readable()) {
            if (pc.pc.read(&c, 1) == 1) {
                handleKey(c);
            }
        }

        // Watchdog: if we were moving but no movement key has refreshed
        // last_cmd_time within HOLD_TIMEOUT, the key was released — stop
        // the motors. Servos are NOT touched: they keep holding their angle.
        if (moving && (cmd_timer.elapsed_time() - last_cmd_time) > HOLD_TIMEOUT) {
            for (int i = 0; i < NUM_MOTORS; i++) duties[i] = 0.0f;
            moving = false;
        }

        for (int i = 0; i < NUM_MOTORS; i++) {
            motors[i]->set_duty(duties[i]);
        }

        // Servo update: rate-limited to one PWM frame (20ms, matches
        // SERVO_FREQ) with a slew-rate ramp toward the target — same
        // smoothing behavior SoftServo used to provide internally.
        if (servo_timer.elapsed_time() >= SERVO_FRAME) {
            servo_timer.reset();

            float max_step = SERVO_MAX_SPEED * SERVO_FRAME_S;
            for (int i = 0; i < NUM_SERVOS; i++) {
                float diff = servo_angles[i] - servo_current[i];
                if (diff > max_step)       diff = max_step;
                else if (diff < -max_step) diff = -max_step;
                servo_current[i] += diff;
                set_servo_angle(i, servo_current[i]);
            }
        }

        // Feedback: duties then servo angles, comma-separated on one line
        // e.g. "0.60,-0.60,0.00,0.00,90.0,-45.0,0.0,135.0\n"
        // Sent through pc (the same BufferedSerial), NOT printf, to avoid
        // two drivers contending for the console UART. Reports the target
        // setpoint (servo_angles), same as before — not the ramped value.
        int len = 0;
        for (int i = 0; i < NUM_MOTORS; i++) {
            if (i > 0) len += snprintf(fb + len, sizeof(fb) - len, ",");
            len += snprintf(fb + len, sizeof(fb) - len, "%.2f", duties[i]);
        }
        for (int i = 0; i < NUM_SERVOS; i++) {
            len += snprintf(fb + len, sizeof(fb) - len, ",%.1f", servo_angles[i]);
        }
        len += snprintf(fb + len, sizeof(fb) - len, "\n");
        pc.send(fb, len);

        wait_us(1000);
    }
}

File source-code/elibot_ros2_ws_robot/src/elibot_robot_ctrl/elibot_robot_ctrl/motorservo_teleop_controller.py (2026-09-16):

"""
Open-loop motor + servo controller ROS2 node — self-contained evdev keyboard.

Same job as the original mbedMotorServoCtrl node (read keys, forward each raw
byte to the Nucleo, publish feedback telemetry), but the keyboard input now uses
the robust evdev method from the enhanced nodes instead of termios/auto-repeat:

  * grabs ALL keyboard-like input devices (exclusive — no keys leak to the
    terminal), so it also works cleanly over SSH / headless;
  * a background thread tracks the live set of physically-held keys via real
    key-down / key-up events (kernel auto-repeat is ignored on purpose);
  * the main loop re-sends every held recognized key over serial at a fixed rate
    (~20 Hz) to feed the firmware's hold-to-move deadman watchdog, then stops the
    instant the key is released.

The Nucleo firmware still owns ALL interpretation (direction, speed scaling,
servo increments/clamping, watchdog) — see combined_node/src/main.cpp. This node
only decides WHICH key bytes to send.

Setup:  pip install evdev   (and be in the 'input' group, or run with sudo)
Quit:   press ESC  (Ctrl+C also works if started with --no-grab)

Change NUM_MOTORS / NUM_SERVOS to match the #defines in mbed main.cpp — only used
to size/validate the feedback line for telemetry, not for any control logic.
"""

import argparse
import selectors
import threading
import time

import rclpy
from rclpy.node import Node
from std_msgs.msg import Float32MultiArray

from elibot_robot_ctrl.SerialSimple import SerialSimple, getFeedbackVals

try:
    from evdev import InputDevice, ecodes, list_devices
except ImportError:
    raise SystemExit("evdev is not installed. Run:  pip install evdev")

# =============================================================
#  Change these to match the #defines in mbed main.cpp
#  (only used to size/validate the feedback line below)
# =============================================================
NUM_MOTORS = 4
NUM_SERVOS = 3

# Every key the firmware recognizes — anything else is never sent over serial.
# See combined_node/src/main.cpp's header comment for what each one does.
MOTOR_KEYS = set('wsadq')
SPEED_KEYS = set('0123456789')
SERVO_KEYS = set('ujikolp;')
CENTER_KEY = 'c'
RECOGNIZED_KEYS = MOTOR_KEYS | SPEED_KEYS | SERVO_KEYS | {CENTER_KEY}

# evdev reports physical keys by name (e.g. KEY_SEMICOLON -> "semicolon").
# Map the ones the firmware wants as punctuation back to their raw char.
ALIASES = {
    'semicolon': ';',
}

SEND_PERIOD = 0.05   # re-send held keys at ~20 Hz (feeds the firmware watchdog)


# ---------------------------------------------------------------------------
#  Keyboard helpers (evdev)
# ---------------------------------------------------------------------------
def key_to_str(code):
    """Convert an evdev key code (KEY_W) to a friendly string ('w')."""
    name = ecodes.KEY.get(code, f'KEY_{code}')
    if isinstance(name, (list, tuple)):
        name = name[0]
    return name[4:].lower() if name.startswith('KEY_') else name.lower()


def normalize_key(code):
    """evdev code -> the single char the firmware expects (or None if unusable)."""
    s = key_to_str(code)
    return ALIASES.get(s, s)


def looks_like_keyboard(dev):
    keys = dev.capabilities().get(ecodes.EV_KEY, [])
    return ecodes.KEY_A in keys and ecodes.KEY_Z in keys and ecodes.KEY_SPACE in keys


def find_keyboards(preferred=None):
    if preferred:
        return [InputDevice(p) for p in preferred]
    found = []
    for path in list_devices():
        try:
            dev = InputDevice(path)
        except OSError:
            continue
        if looks_like_keyboard(dev):
            found.append(dev)
    return found


def reader_thread(devices, pressed, lock, stop_event):
    """Maintain the set of currently-held RECOGNIZED key chars. ESC -> quit."""
    sel = selectors.DefaultSelector()
    for dev in devices:
        sel.register(dev.fd, selectors.EVENT_READ, dev)
    try:
        while not stop_event.is_set():
            for sk, _ in sel.select(timeout=0.1):
                dev = sk.data
                try:
                    for event in dev.read():
                        if event.type != ecodes.EV_KEY:
                            continue
                        if event.value == 1:            # key down
                            if event.code == ecodes.KEY_ESC:
                                stop_event.set()
                                return
                            ch = normalize_key(event.code)
                            if ch in RECOGNIZED_KEYS:
                                with lock:
                                    pressed.add(ch)
                        elif event.value == 0:          # key up
                            ch = normalize_key(event.code)
                            if ch in RECOGNIZED_KEYS:
                                with lock:
                                    pressed.discard(ch)
                        # value == 2 (kernel auto-repeat) ignored — we do our own
                except OSError:
                    stop_event.set()
                    return
    finally:
        sel.close()


# ---------------------------------------------------------------------------
#  ROS2 node
# ---------------------------------------------------------------------------
class MotorServoController(Node):
    def __init__(self):
        super().__init__('mbedMotorServoCtrl')
        self.duty_publisher  = self.create_publisher(Float32MultiArray, 'motor_duty', 10)
        self.servo_publisher = self.create_publisher(Float32MultiArray, 'servo_angle', 10)
        self.timer = self.create_timer(0.02, self.timer_callback)   # 50 Hz telemetry
        self.duties = [0.0] * NUM_MOTORS
        self.angles = [0.0] * NUM_SERVOS

    def timer_callback(self):
        duty_msg = Float32MultiArray()
        duty_msg.data = self.duties
        self.duty_publisher.publish(duty_msg)

        servo_msg = Float32MultiArray()
        servo_msg.data = self.angles
        self.servo_publisher.publish(servo_msg)
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

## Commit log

2026-09-16 Add source code to the repo: firmware + ROS2 stack
    - STM32 firmware (combined_node final build, motors_only/servos_only
    debug isolation builds), with unused Servo/SoftServo libs removed
    from combined_node and motors_only/servos_only key mappings synced
    to match combined_node (they had drifted out of sync, contradicting
    their own "verbatim copy" header comments).
    - ROS2 workspace deployed on the robot (camera, vision, teleop), with
    a broken cross-package import fixed and missing package.xml
    dependencies added.
    - ROS2 workspace for optional off-robot vision deployment, with the
    two orphaned/incompatible standalone nodes removed and a docstring
    explaining how it pairs with the r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
    [SerialSimple.py, main.cpp, motorservo_teleop_controller.py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]
2026-09-16 Rename ml3_* packages/folders to elibot_* / drop ML3 branding
    Renamed throughout the source tree so the project's own name (ELIBot)
    replaces the course-code "ml3" prefix everywhere it appeared in code:
    - ROS2 packages: ml3_camera -> elibot_camera, ml3_vision -> elibot_vision
    (both workspace copies), ml3_robot_ctrl -> elibot_robot_ctrl, with all
    package.xml names/dependencies, setup.py package names/entry_points/
    maintainer fields, setup.cfg paths, the launch file's package
    references, and cross-file docstring mentions updated to match.
    - Workspaces: ml3_ros2_ws_robot -> elibot_ros2_ws_robot,
    ml3_ros2_ws_server -> elibot_ros2_ws_server.
    - Firmware folder: ML3_Nucleo_Projects -> Nuc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
    [SerialSimple.py, main.cpp, motorservo_teleop_controller.py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]
2026-09-16 Restore course/competition context in the README
    The previous trim cut too much - it lost the connection between the
    robot and why it looks the way it does (built for a university course's
    15th-week robot challenge). Add that context back while still leaving
    out the scoring/rules specifics.
2026-09-16 Correct teleoperation description: fixed course cameras, not onboard-only
    The operator's primary view was fixed cameras placed along the course
    (shown on a multi-window monitor), not the robot's own onboard camera -
    the onboard feed was an optional supplement viewed separately. The
    previous wording implied the onboard camera was the operator's main or
    only view, which overstates its role.
2026-09-16 Add project documents: final report, challenge rules, presentations
    Adds the four PDFs the README already links to under Documents:
    final report, challenge & field rules, the original concept pitch, and
    the intermediate checkpoint presentation. Skipping the .pptx source
    files (PDFs already cover viewing) and the Final Presentation video
    (477MB, over GitHub's file size limit) for now.
2026-09-16 Rename concept/intermediate presentations to flag superseded design
    Both PDFs document earlier, abandoned design iterations rather than the
    final ELIBot: the concept presentation pitches the original tri-wheel
    robot, and the intermediate presentation is a mid-project checkpoint
    showing the tri-wheel-to-four-wheel pivot partway through (it still
    shows the pincher end effector that was later replaced by a hook).
    Renamed both files to say so explicitly, and updated the README's
    Documents section and repo-structure comments to match.
2026-09-16 Correct Design Journey to reflect all three mechanical design stages
    There were three designs, not two: tri-wheel (original concept), then
    four-wheel with only the front pair spiked (the second design, which
    the Intermediate Presentation actually documents the transition to),
    and finally four-wheel with all four wheels spiked. The switch to
    design 3 was driven by the second design's plain rear wheels not
    gripping well enough to climb the stairs.
2026-09-16 Drop Old Design/ from the repo plan; keep older designs presentation-only
    The raw CAD/image/video files for the tri-wheel and front-only-spiked
    designs won't be uploaded (incomplete/uncertain set, and the repo is
    meant to hold the final prototype's actual files). Design history for
    stages 1 and 2 stays documented through the two presentations and the
    README's Design Journey section only.
2026-09-16 Add Media section with the Stage II official run video
    Adds a new Media section (Documents stays for written/presentation
    deliverables) linking the full Stage II competition run footage,
    hosted on Google Drive due to file size (2GB).
2026-09-17 Add final prototype photos to the repo and README gallery
    Renames the 9 WhatsApp-exported robot photos in Media/Pictures/Robot
    Pictures/ to descriptive names and tracks them in git, then adds a
    Photos gallery under the new Media section in the README. The .HEIC
    originals in that folder are left untouched/untracked (out of scope).
2026-09-17 Add wheel STL files: inner hub and outer claw ring
    The clawed/spiked wheel's two printed parts: the rigid PLA inner hub
    (mounts to the motor shaft) and the flexible TPU outer claw ring.
    [Inner Part of Wheel.stl, Outer Claw Wheel.stl]
2026-09-17 Rename wheel STL files to a consistent, material-labeled style
    [Wheel Inner Hub (PLA).stl, Wheel Outer Claw Ring (TPU).stl]
2026-09-17 Add Top Chassis STL under a new Robot Body folder
    Moved from the old standalone Lid/Lid2.stl and renamed to match the
    final report's terminology (Figure II labels this part "Top Chassis",
    not "lid").
    [Top Chassis.stl]
2026-09-17 Align wheel filenames and README wording with the final report
    - Renamed the two wheel STL files to match the report's own figure
    captions ("Inner part of the wheel made from PLA" / "Outer wheel
    made from TPU") instead of the invented "hub"/"claw ring" terms,
    which don't appear in the report at all.
    - Fixed the README's Mechanical section, which contradicted the
    report by describing one generic "Chassis" with a "lid" and one
    generic "Brackets" — the report (Figure II, §2.1.1) actually names
    four distinct parts: Top Chassis, Bottom Chassis, (main) Brackets,
    and Support Brackets.
    [Inner Part of the Wheel (PLA).stl, Outer Wheel (TPU).stl]
2026-09-17 Point to final report §2.4 for the circuit design/wiring details
2026-09-29 Add Robot Body STL files, aligned with final report terminology
    Adds Cage, Bottom Chassis, and all four bracket pairs (front/rear x
    main/support). Fixed a "Chasis" typo in the two chassis files (also
    updates Top Chassis.stl with a newer export), and renamed the rear
    bracket files from "Back-*" to "Rear-*" to match the report's own
    wording (§2.1.1: "front main brackets", "rear brackets").
    [Bottom Chassis.stl, Cage.stl, Front-Left Bracket.stl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]
2026-09-30 Add manipulator arm STL files
    Base/Middle/Top links plus the Hook end effector for the final 1-DOF
    "elephant trunk" manipulator arm (see final report §2.3). Renamed
    "Hook.stl" to "Manipulator Hook.stl" and fixed a capitalization
    inconsistency in "Manipulator Top part.stl" for consistency with its
    sibling files.
    [Manipulator Base Part.stl, Manipulator Hook.stl, Manipulator Middle Part.stl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]
2026-09-30 Add Stage I practice run video link to Media/Videos
2026-09-30 Pre-publish polish pass
    - Sync setup.py descriptions with their package.xml counterparts
    (three still said "TODO: Package description").
    - Add LICENSE and Videos/Photos to the README's Repository Structure
    tree and Table of Contents, which had drifted out of sync with the
    actual repo as content was added incrementally.
    - Fix STL Files repo-structure comment (said "STL/gcode" but only STL
    files were ever added).
